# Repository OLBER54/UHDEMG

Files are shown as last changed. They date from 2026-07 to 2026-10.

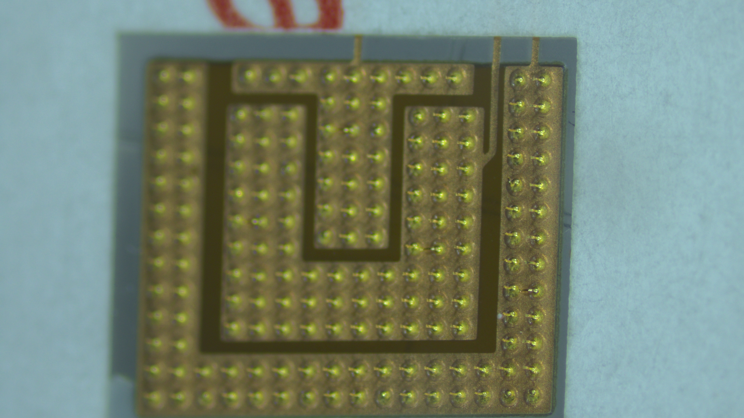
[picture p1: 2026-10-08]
Photos/UNeedles Sample/Tilt_Right_2.png

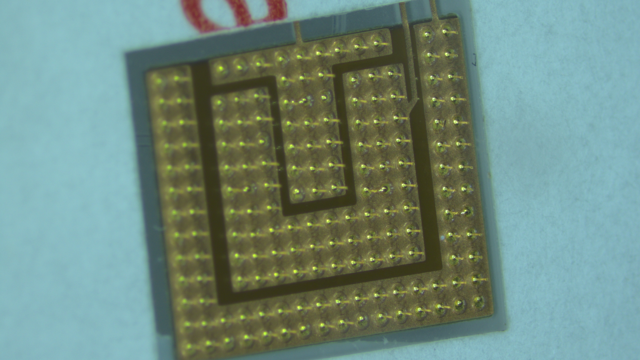
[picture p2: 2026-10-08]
Photos/UNeedles Sample/Tilt_Left_2.png

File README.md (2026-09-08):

Ultra-High-Density EMG Electrode Array
Development of an ultra-high-density electrode array for myoelectric signal acquisition and analysis, with a target of up to 512 electrodes spaced 5 mm apart. 
This project explores the use of a dense microneedle electrode array to support the evaluation of electromyography (EMG) signal analysis methods. Its motivating application is the control of hand prostheses using electrical signals generated by muscles.
The project addresses the limited electrode count and density highlighted in the project presentation, with the aim of providing a platform for more detailed analysis of muscle activity.

Objectives
- Develop an ultra-high-density electrode array for myoelectric signal acquisition.
- Evaluate and validate the performance of myoelectric signal analysis algorithms.
- Investigate EMG decomposition methods for studying motor unit activity.

Target Specifications
- Electrode count:	Up to 512
- Electrode: spacing	5 mm
- Electrode interface:	Microneedles at each electrode (23 microneedles per electrode)
- Recorded signals:	EMG
- Analysis focus: Algorithm evaluation and motor unit decomposition

Potential Applications
- Myoelectric hand prosthesis control.
- Muscle rehabilitation.
- Research supporting neurological disease diagnosis.

Files Architecture
- Archive: Old files
- Code: FPGA Verilog files, C++ PC application for collecting data and Matlab code for motor unit decomposition
- Presentations: Journal club, progess meeting and project summary
- Template Project Folder: Template used for altium projects
- UHDEMG: Electronic and mechanical files

PCB projects are on UHDEMG\01 - SCHEMAS ET PCB\99 - WORKING COPY
PCB Projects:
- DB_Panel: PCB panel of FPGA_DB and Electrode_Breakout
- Electrode_Breakout: PCB that connect to the electrode with headers on it.
- FPGA_DB: FPGA breakout board. Used to connect the FPGA to the INTAN modules boards
- RHD2132_64CH: INTAN modules to sample raw EMG data. Since the RHD2164 is not available, 2x RHD2132 are used in parallel to replace it. Up to 8 boards can be used at the same time to reach up to 512 electrodes.
- Microneedle_Patch: Flexible circuit board where microneedles are installed. 32 electrodes per FPC.
- Microneedle_Patch_Mirrored: Same as Microneedle_Patch, but the tail goes the other way, allowing to connect 64 electrodes to one RHD2132_64CH board.

Global_Project_Diagram

Electrode_Breakout_Diagram

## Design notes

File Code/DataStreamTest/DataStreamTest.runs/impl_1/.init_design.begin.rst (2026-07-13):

<?xml version="1.0"?>
<ProcessHandle Version="1" Minor="0">
    <Process Command=".planAhead." Owner="olivi" Host="LAPTOP-H85DCTKA" Pid="26048">
    </Process>
</ProcessHandle>

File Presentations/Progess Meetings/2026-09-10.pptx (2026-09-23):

## Updates

2026-09-10

## Design Issues

- RHD2164: B.O.
  - Had to redesign some of the boards
  - Main change: 1x RHD2164 -> 2x RHD2132
- All the redesigns are done
  - PCB review: In progress
  - BOM: Waiting on 1 quote only (RHD2132)

## Design Issue (Before)

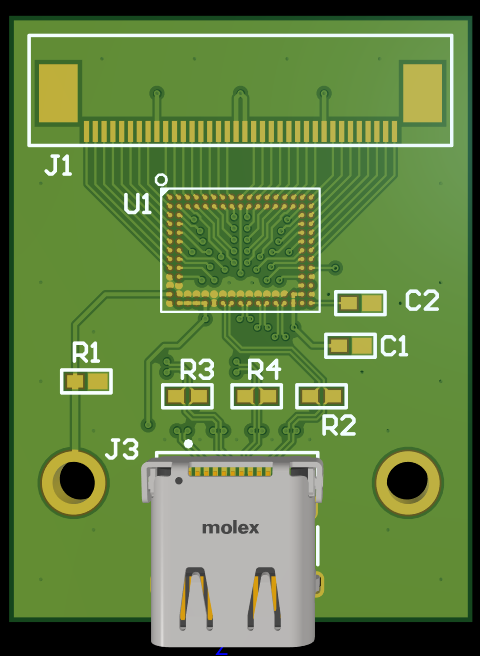
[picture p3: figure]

## Design Issue (After)

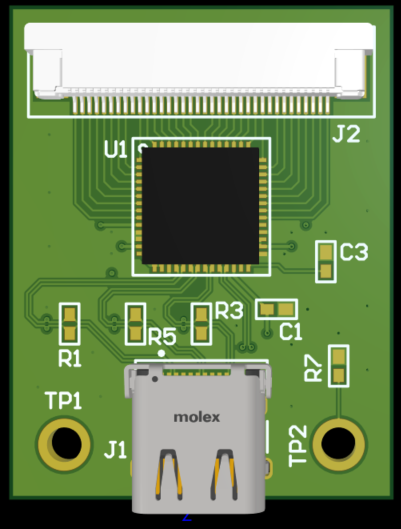
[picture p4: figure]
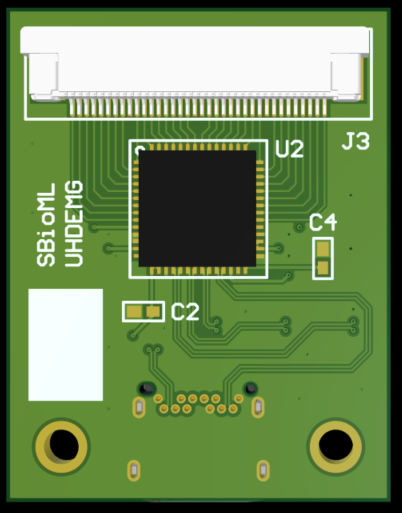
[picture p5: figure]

## Design Issue (Before)

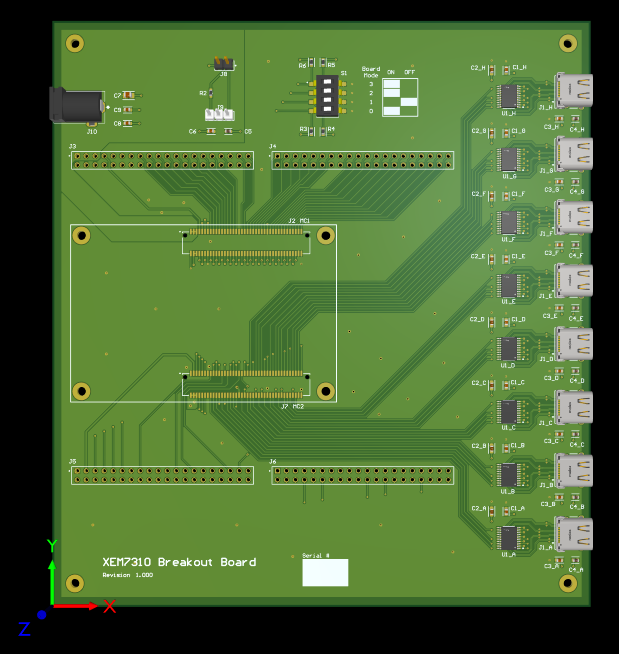
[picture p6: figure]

## Design Issue (After)

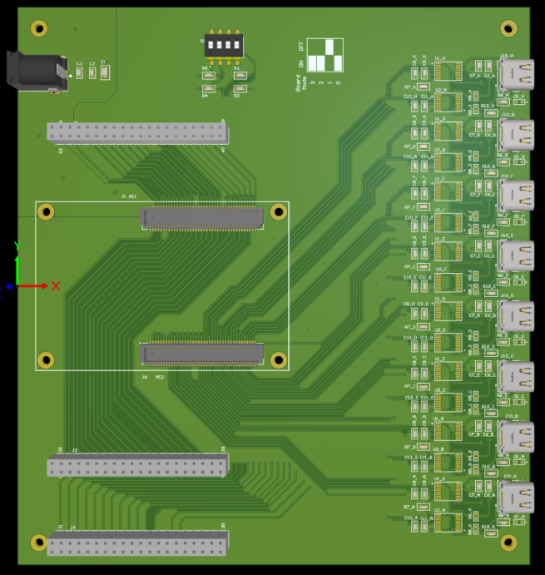
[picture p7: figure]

## Mechanical Setup

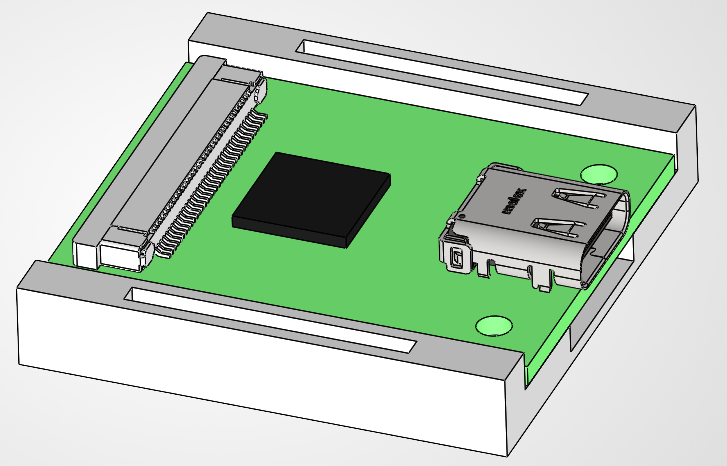
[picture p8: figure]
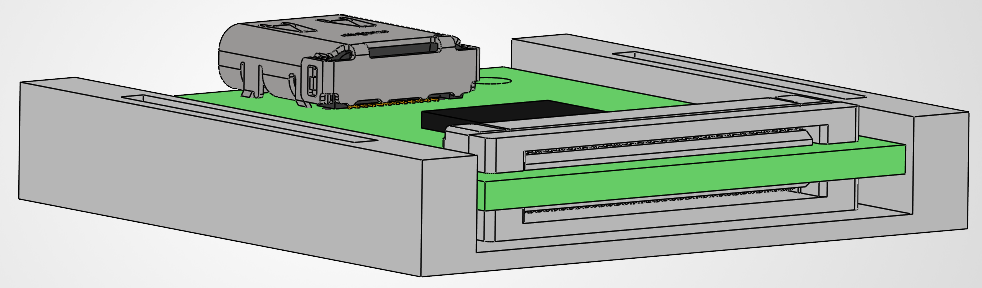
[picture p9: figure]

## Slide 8

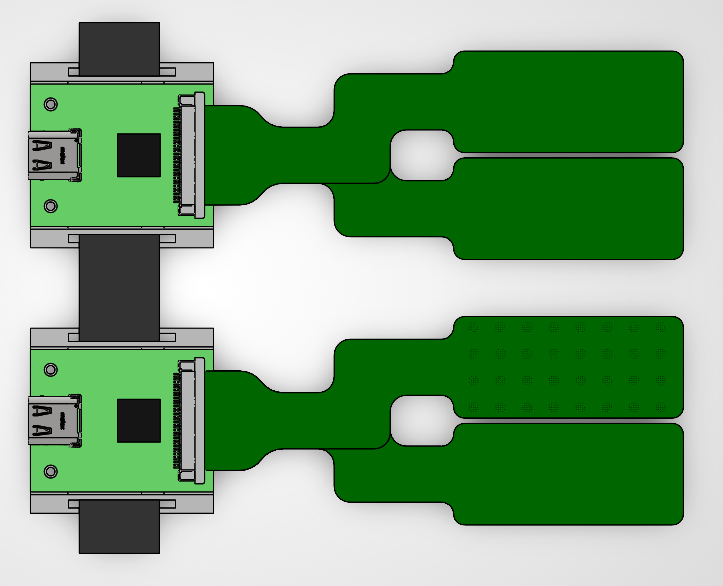
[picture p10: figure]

Hand

Elbow

## Next steps

- Scholarships applications
- PCB Review / Correct the designs / Order
- Test plans and protocol preparation
- Prepare code for collecting data

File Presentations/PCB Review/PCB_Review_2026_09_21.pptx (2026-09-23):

## PCB Review

Olivier Bergeron
2026/09/21

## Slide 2

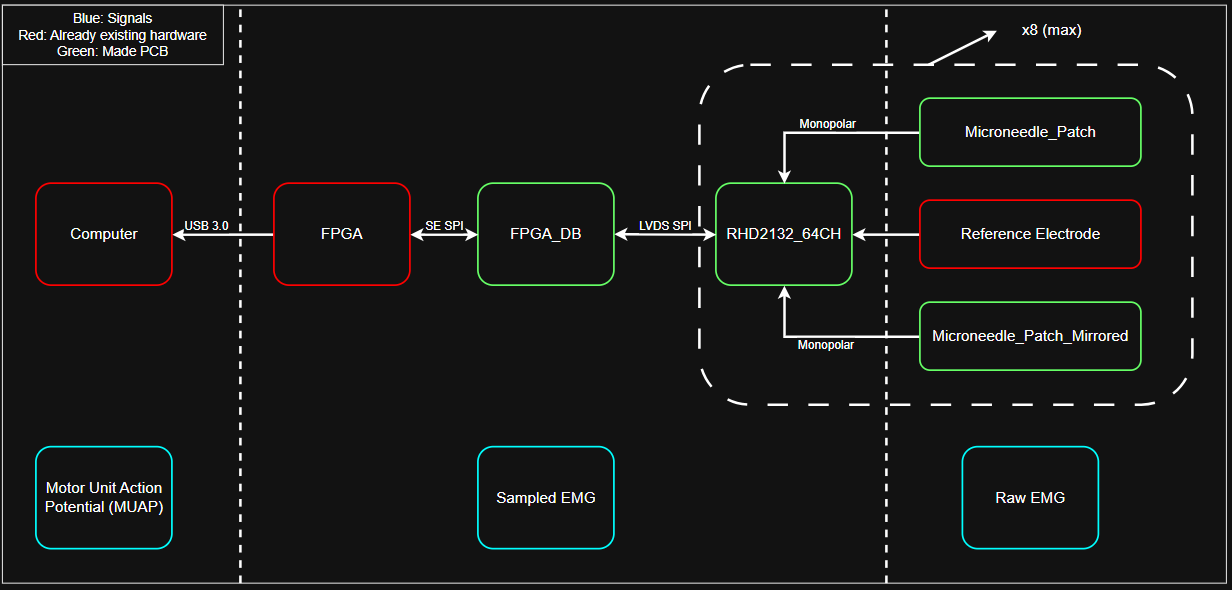
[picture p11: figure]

## Electrode Parameters

- Electrode
  - 2.5 mm diameter
  - 5 mm IED
  - 23 microneedle/electrode
    - 50 µm diameter
    - 400 µm long

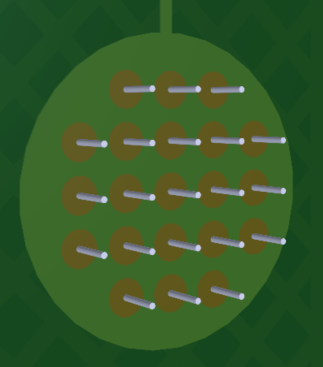
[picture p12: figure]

## Electrode Grid

- Grid size
  - 8 x 4
- For 1 patch
  - 32 electrodes
  - Up to 16 patches (512)
- Reference electrode
  - External Ag/AgCl

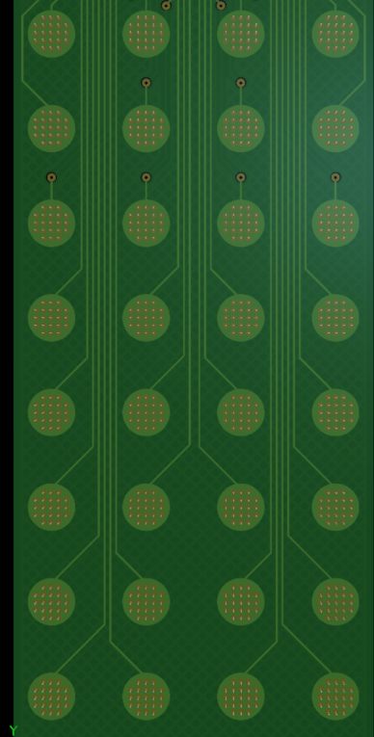
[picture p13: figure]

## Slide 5

Hand

Elbow

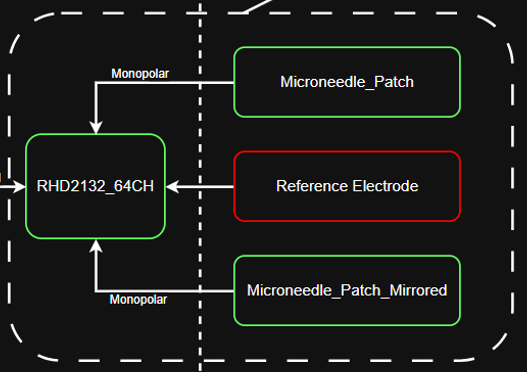
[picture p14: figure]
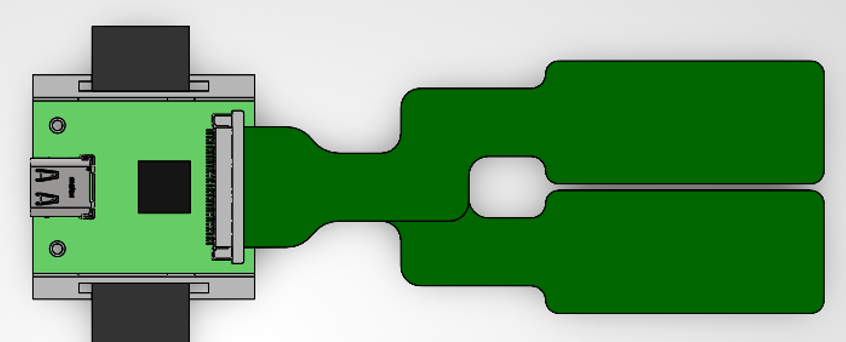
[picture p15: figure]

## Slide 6

Hand

Elbow

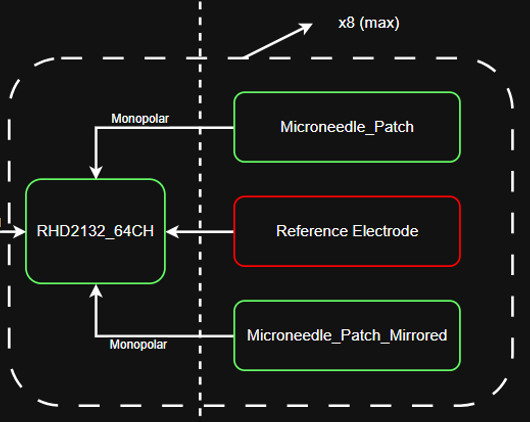
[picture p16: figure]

## From INTAN to FPGA

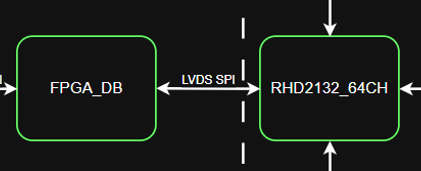
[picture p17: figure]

- For each RHD2132_64CH
  - 1 USB cable to FPGA board
  - 2x RHD2132 per board

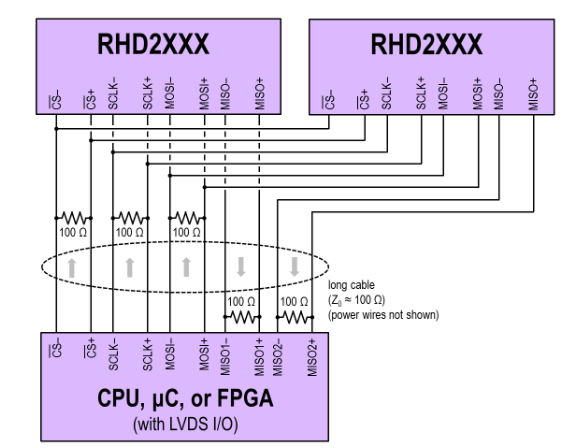
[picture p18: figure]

## From INTAN to FPGA

- 5 signals to transport
  - Can’t use the cable with redundancy
  - Need to check polarity
- Enable drivers with right polarity

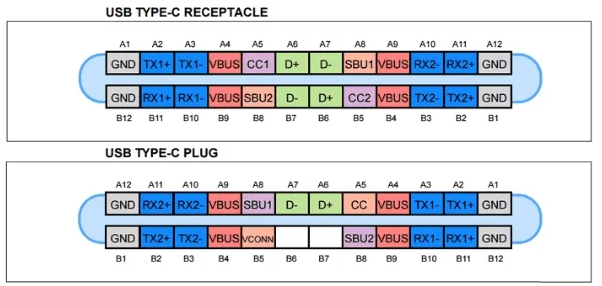
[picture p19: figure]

## From INTAN to FPGA

- FPGA Side
  - SBU 1: EN
  - SBU 2: EN
- RHD2132 Side
  - SBU 1: 3V3
  - SBU 2: 0V

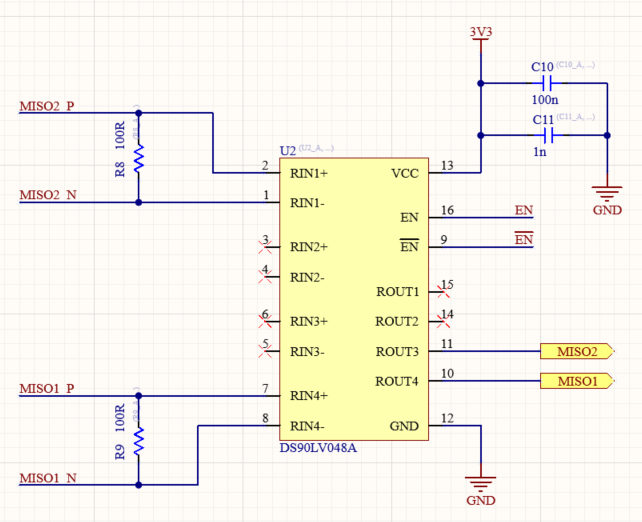
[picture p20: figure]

## FPGA Daughter Board

- USB connectors
  - Connect with RHD2132
- LVDS Drivers/Receivers
  - FPGA: Single Ended
  - RHD2132: LVDS

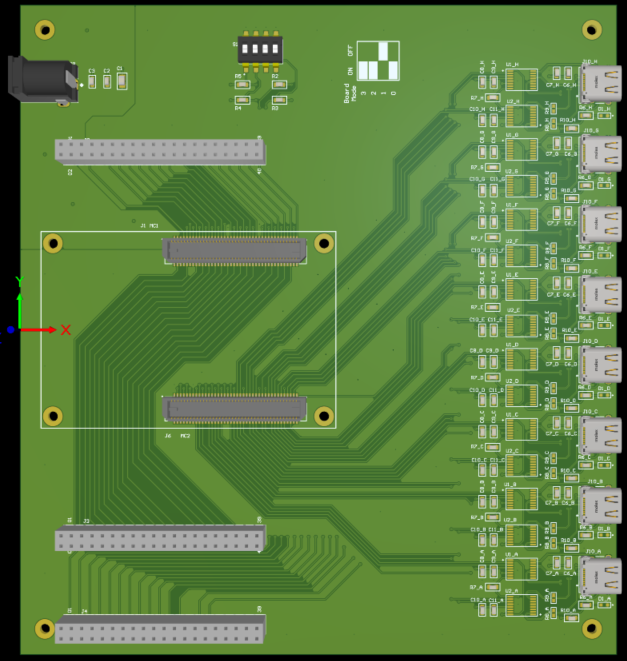
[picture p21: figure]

## Electrode Breakout Board

- For individual testing of electrode patches

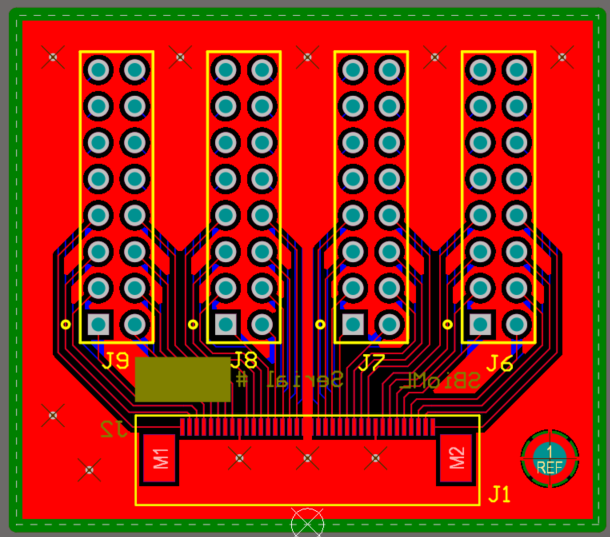
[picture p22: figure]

## Stackups

- FPGA_DB
  - Standard 4 layers PCB
  - 100 Ohms impedance (LVDS)
- Electrode Breakout
  - Standard 4 layers PCB

- RHD2132_64CH
  - 6 layers PCB
  - 100 Ohms impedance (LVDS)
- Electrode Patches
  - 2 layers FPC

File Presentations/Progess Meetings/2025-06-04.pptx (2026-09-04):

## Ressearch on benefits on higher electrode count on HD-EMG

## Is more better?

- Yes and no
- TL;DR
  - More will always be more precise
  - Diminishing returns
  - Algorithm dependant

## Main focus of articles

- Main focus of articles on HD-EMG: Reaching optimal number of electrode for algorithm, not density

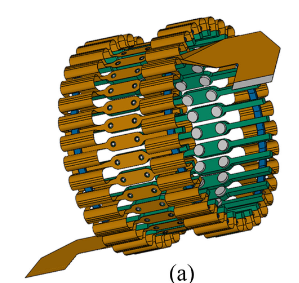
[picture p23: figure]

G. Rolandino, C. Zangrandi, T. Vieira, G. Luigi Cerone, B. Andrews, et J. J. FitzGerald, « HDE-Array: Development and Validation of a New Dry Electrode Array Design to Acquire HD-sEMG for Hand Position Estimation », IEEE Trans. Neural Syst. Rehabil. Eng., vol. 32, p. 4004‑4013, 2024, doi: 10.1109/tnsre.2024.3490796 (https://doi.org/10.1109/tnsre.2024.3490796).

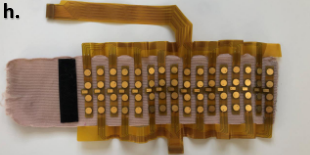
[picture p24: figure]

F. Chamberland et al., « Novel Wearable HD-EMG Sensor With Shift-Robust Gesture Recognition Using Deep Learning », IEEE Trans. Biomed. Circuits Syst., vol. 17, no 5, p. 968‑984, oct. 2023, doi: 10.1109/TBCAS.2023.3314053 (https://doi.org/10.1109/TBCAS.2023.3314053).

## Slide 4

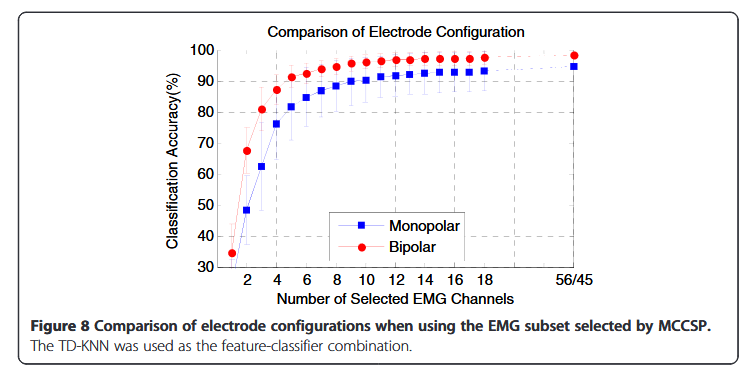
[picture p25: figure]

Y. Geng, X. Zhang, Y.-T. Zhang, et G. Li, « A novel channel selection method for multiple motion classification using high-density electromyography », BioMed Eng OnLine, vol. 13, no 1, p. 102, déc. 2014, doi: 10.1186/1475-925X-13-102 (https://doi.org/10.1186/1475-925X-13-102).

21 hand movements

Note: Some electrodes are on the hand for this study

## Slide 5

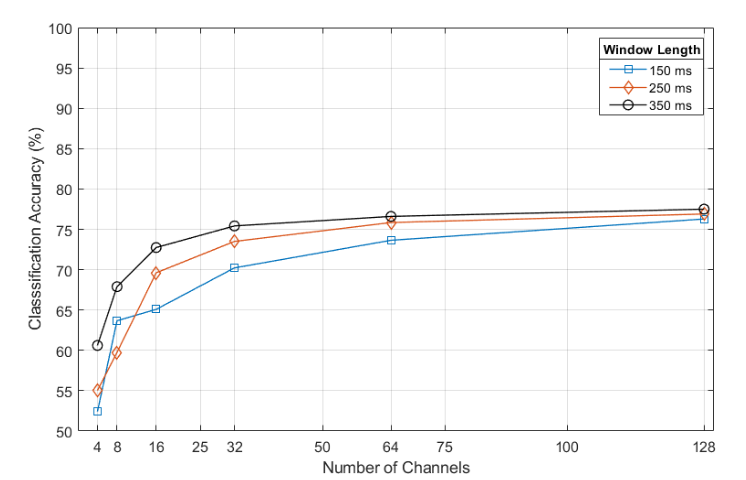
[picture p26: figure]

J. Lara, N. Paskaranandavadivel, et L. K. Cheng, « Effect of Segmentation Parameters on Classification Accuracy of High-Density EMG recordings », in 2019 41st Annual International Conference of the IEEE Engineering in Medicine and Biology Society (EMBC), Berlin, Germany: IEEE, juill. 2019, p. 6229‑6232. doi: 10.1109/EMBC.2019.8856809 (https://doi.org/10.1109/EMBC.2019.8856809).

9 hand movements

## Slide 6


M. Paleari, M. Di Girolamo, N. Celadon, A. Favetto, et P. Ariano, « On optimal electrode configuration to estimate hand movements from forearm surface electromyography », in 2015 37th Annual International Conference of the IEEE Engineering in Medicine and Biology Society (EMBC), Milan: IEEE, août 2015, p. 6086‑6089. doi: 10.1109/EMBC.2015.7319780 (https://doi.org/10.1109/EMBC.2015.7319780).

11 hand movements

J. Lara, N. Paskaranandavadivel, et L. K. Cheng, « HD-EMG Electrode Count and Feature Selection Influence on Pattern-based Movement Classification Accuracy », in 2020 42nd Annual International Conference of the IEEE Engineering in Medicine & Biology Society (EMBC), Montreal, QC, Canada: IEEE, juill. 2020, p. 4787‑4790. doi: 10.1109/EMBC44109.2020.9175210 (https://doi.org/10.1109/EMBC44109.2020.9175210).

17 hand movements

## Consequence of main focus

- Use of commercial hardware
- If focused on quantity: not focused on positionning


M. Paleari, M. Di Girolamo, N. Celadon, A. Favetto, et P. Ariano, « On optimal electrode configuration to estimate hand movements from forearm surface electromyography », in 2015 37th Annual International Conference of the IEEE Engineering in Medicine and Biology Society (EMBC), Milan: IEEE, août 2015, p. 6086‑6089. doi: 10.1109/EMBC.2015.7319780 (https://doi.org/10.1109/EMBC.2015.7319780).


J. Lara, N. Paskaranandavadivel, et L. K. Cheng, « Effect of Segmentation Parameters on Classification Accuracy of High-Density EMG recordings », in 2019 41st Annual International Conference of the IEEE Engineering in Medicine and Biology Society (EMBC), Berlin, Germany: IEEE, juill. 2019, p. 6229‑6232. doi: 10.1109/EMBC.2019.8856809 (https://doi.org/10.1109/EMBC.2019.8856809).

## Key design points

- Electrode geometry
- Inter-electrode distance (IED)
- Optimal resolution
- Computing power

## Electrode Geometry

- 2 main geometry
  - Pin: Circular electrode
  - Bar: Rectangular electrode
- Smaller electrode: Lower SNR
- Bigger electrode: Less precise information on signal and higher chance of crosstalk

## Inter-electrode distance (IED)

- IED: center to center distance between two electrodes
- Higher IED values: Higher chance of crosstalk and lower density
- Lower IED values: Lower SNR
  - Less impact on SNR than electrode dimensions

## Optimal resolution

- Resolution gain with adding electrodes:
  - Along the muscle fiber: small
  - Perpedicular to muscle fibers: big

## Computing power

- Higher quantity of electrodes: More computing power
- Main limiting factor for portable bracelet

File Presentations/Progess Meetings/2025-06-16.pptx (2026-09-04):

## Update

Olivier Bergeron
2025-06-16


## Trends looked for

- Number of electrodes vs electrode size
- Number of electrodes vs IED (Inter-electrode distance)
- Number of electrodes vs quantity of movement evaluated
- All of them were evaluated for a specific classification accuracy (90%)
- Major difficulty: only found 5 papers on varying electrode count and accuracy

## Trends looked for

- Quick conclusions:
  - Never the same amount of electrodes
  - Always a smart selection/position of electrodes
  - No paper got the same maximum classification accuracy
  - Some papers put electrodes on the hand
- Trends appear when taking in count percentage of electrode instead of absolute number of electrodes and classification accuracy relative to its max

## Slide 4


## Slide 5


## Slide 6


Logic trend: smaller electrodes -> lower signal amplitude -> need more electrodes

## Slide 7


Logic trend: closer electrodes -> smaller electrodes -> lower signal amplitude -> need more electrodes

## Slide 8


Trend seems to look like more movements requires a little more electrodes

## Next trend to look for

- Number of detectable motor units vs number of electrodes
- As of right now: only found 1 paper
A. H. Caillet et al., « Larger and Denser: An Optimal Design for Surface Grids of EMG Electrodes to Identify Greater and More Representative Samples of Motor Units », eNeuro, vol. 10, no 9, p. ENEURO.0064-23.2023, sept. 2023, doi: 10.1523/ENEURO.0064-23.2023 (https://doi.org/10.1523/ENEURO.0064-23.2023).

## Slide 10


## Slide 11


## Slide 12


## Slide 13


## Partial conclusions

- Going denser:
  - Tends to give a little more accuracy
  - Seems to give more detectable motor units

## Next steps

- Keep trying to find papers on motor unit detection vs quantity of electrodes

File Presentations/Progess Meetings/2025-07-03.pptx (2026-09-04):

## Updates

Olivier Bergeron


## Since last time

- Two main goals
  - 1- Keep searching for articles for correlation between electrode count and classification accuracy
    - Didn’t find any more valuable article as of right now
  - 2- Find more articles about motor unit decomposition

## Motor Unit

- Definition: A motor unit consist of a motor neuron and all the muscle fibers innervated by the axon.
- Smallest functional unit of voluntary muscle activation


S. K. Gollapudi, J. J. Michael, and M. Chandra, Striated Muscle Dynamics, Reference Module in Biomedical Sciences. Elsevier, 2014. doi: 10.1016/B978-0-12-801238-3.00251-8 (https://doi.org/10.1016/B978-0-12-801238-3.00251-8).

## Motor unit vs EMG


D. Farina et A. Holobar, « Characterization of Human Motor Units From Surface EMG Decomposition », Proc. IEEE, vol. 104, no 2, p. 353‑373, févr. 2016, doi: 10.1109/JPROC.2015.2498665 (https://doi.org/10.1109/JPROC.2015.2498665).

## Motor Unit Decomposition

- Multiples techniques for extracting motor units spike trains
  - Blind Source Separation
    - Separates mixed signals into their original independent sources without prior knowledge of the mixing process.
  - Convolution Kernel Compensation
    - Reconstructs motor unit spike trains by compensating for the convolution effect of motor unit action potentials in EMG signals.
  - Template matching + clustering
    - Detects and classifies recurring signal patterns (spikes) by comparing them to learned templates and grouping similar ones into clusters.

## What information can be extracted

- Firing rate of motor units
- Recruitment order
- Spike timing
- Spatial location

## Pros with motor unit decomposition

- Ability to find subtle gestures
  - Some EMG patterns overlap for different motor unit activity
- High quantity of recognisable gestures with high classification accuracy
  - Example of quantity of gestures: 12 (94.6%)¹, 66 (≥ 89%)²
- High classification accuracy
  - Around the same as CNN

[1] C. Chen, Y. Yu, X. Sheng, J. Meng, et X. Zhu, « Real-Time Hand Gesture Recognition by Decoding Motor Unit Discharges Across Multiple Motor Tasks From Surface Electromyography », IEEE Trans. Biomed. Eng., vol. 70, no 7, p. 2058‑2068, juill. 2023, doi: 10.1109/TBME.2023.3234642 (https://doi.org/10.1109/TBME.2023.3234642).
[2] M. Montazerin, E. Rahimian, F. Naderkhani, S. F. Atashzar, S. Yanushkevich, et A. Mohammadi, « Transformer-based hand gesture recognition from instantaneous to fused neural decomposition of high-density EMG signals », Sci Rep, vol. 13, no 1, p. 11000, juill. 2023, doi: 10.1038/s41598-023-36490-w (https://doi.org/10.1038/s41598-023-36490-w).

## Cons with motor unit decomposition

- Highly sensitive to electrode shift
  - Often required to re-decompose the motor units when shifting happens
- More “hardware hungry”
  - Decompositions methods are more computationally intensive
  - More power is needed
  - Very difficult for real-time application
- Highly sensitive to positioning
  - Misalignments/changes in contact degrades motor unit tracking quality
  - When redonned, recalibration is required

## What if: hybrid method

- Hybrid method: Combine motor unit decomposition with CNN features
- Why?
  - Robustness, fast computing and general hand gestures with CNN
  - Fine neural control details with motor unit decomposition

## What if: hybrid method

- Methods examples
  - Early fusion: Concatenate EMG + Motor Unit into one input
  - Late fusion: Two separate classifier fused at decision level
  - Joint fusion: Models with dual-branches and adaptive weighting
- Applications
  - High gesture count applications
  - Benchmarking upper limits of classification performance

## Pros and Cons

- Pros
  - Combining increase accuracy
  - More gesture recognition
  - Can give neural control information
- Cons
  - High computing cost
  - Very hard for wearable devices
  - High sensibility with steep performance reduction risk

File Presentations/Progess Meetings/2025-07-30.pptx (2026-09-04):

## Avancements

Olivier Bergeron


## Since last time

- Project finally got defined
  - Design a HD-EMG forearm sleeve with high count of electrodes (≥ 256 channels) aimed at detecting and decomposing motor unit activity to enable accurate hand movement recreation in an offline environment.
  - Definition still w.i.p.
- Start defining project needs/goals
  - Multiple categories
    - Mechanical
    - Electronics
    - Firmware
    - Software

## Mechanical Design

- First major design phase
- Sleeve design
  - Structure (Material, Shape, Size)
  - Electrode design (Material, Size, Positioning, Quantity)
  - Cable management
  - Ease of use
- Design approach: Custom

## Electronic Design

- Second major design phase
- Data acquisition design
  - Acquisition module (Data to be read by an FPGA)
  - FPGA module for acquisition
  - GPU module for software use
- Design approach: Not fully defined, but might go with overkill already existing design (try to avoid having it as a bottleneck)

## Firmware Design

- Third major design phase
- Data acquisition code
  - Program the FPGA to get all the channels and transfer the data to a GPU
  - Sampling frequency objective: 2 kHz

## Software Design

- Last major design phase
- Algorithm implementation
  - Use of motor unit decomposition algorithms to reconstruct hand movements

## Some start of mechanical design

- Context: Electrodes needs to be small and close to each other for motor unit decomposition
- Rule of thumb: IED ≈ 2 x Electrode diameter
  - With a small electrode diameter
    - More motor units will be detectable
    - Noisier the signal will be
    - Sweet spot seems to be between 2 mm and 4 mm

## Some start of mechanical design

- Example
  - 265 mm circumference where the sleeve will be
  - With an IED of 4 mm => approx. 67 electrodes needed for 1 row of electrodes
  - If we want 256 electrodes max => only 3 columns are possible
- Three possible approaches:
  - 1- More electrodes
  - 2- Increase IED (Higher and/or asymmetrical values)
  - 3- Half sleeve instead of full sleeve

## Some start of mechanical design

- What have been found so far
  - Avoid half sleeve because of less detectable motor units
  - Asymmetrical IED values, since circumferential coverage is more important than longitudinal coverage
  - To keep electrodes small and close, higher electrode count will be needed
- First draft: 60 x 8 grid with circumferential IED close to 4 mm and longitudinal IED of 10 mm

## Next steps

- Figure out if there is a maximum of channels electronic wise
- Try different grid values
- Simulate coverage when forearm size change

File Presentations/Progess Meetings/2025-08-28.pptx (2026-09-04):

## Update

Olivier Bergeron
28/08/2025


## Since last time

- Last grid draft:
  - 61 x 8 electrodes
  - 488 electrodes in total
  - 2 mm diameter
  - Circumference IED = [4; 5] mm
  - Length IED = 10 mm

## Modifications

- Problem with rectangular grid: non uniform IED
  - The further from the muscle belly, the closer the electrodes
  - Solution: Lower the electrode count for the rows further from the belly
- Other modification: remove the last row
  - Goal: Reduce the electrode count without any major impact

## Modifications

- Problem with rectangular grid: non uniform IED
  - The further from the muscle belly, the closer the electrodes
  - Solution: Lower the electrode count for the rows further from the belly
- Problem with IED constrain not enough wiggle room for covering average sizes
  - Size range (circumference) = [210; 290] mm
  - Solution: 2 sizes
- Other modification: remove the last row
  - Goal: Reduce the electrode count without any major impact

## Modifications

- Problem with rectangular grid: non uniform IED
  - The further from the muscle belly, the closer the electrodes
  - Solution: Lower the electrode count for the rows further from the belly
- Problem with IED constrain not enough wiggle room for covering average sizes
  - Size range at maximum size (circumference) = [210; 290] mm
  - Solution: 2 sizes
- Other modification: remove the last row
  - Goal: Reduce the electrode count without any major impact

## New draft


Note:
Minimal coverage: Minimum arm size (IED = 4 mm)
Maximal coverage: Maximum arm size (IED = 5 mm)
Initial Draft: 488 electrodes in total

## Next Steps

- Scholarship applications (W.I.P.)
- 3D view of the sleeves (W.I.P.)
- Start looking at electrode fabrication processes

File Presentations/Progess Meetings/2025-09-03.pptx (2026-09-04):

## Objectif

- Objectif: Reconstruction des mouvements de la main à l’aide de la decomposition des signaux EMG en potentiel d’action d’unités motrice (MUAP)


D. Farina et R. Merletti, Éd., Surface electromyography: physiology, engineering, and applications. in IEEE Press Series on Biomedical Engineering. Piscataway, NJ: IEEE Press, 2016. doi: 10.1002/9781119082934 (https://doi.org/10.1002/9781119082934).

## Cahier des charges

- Électrodes
  - Diamètre: 2 mm
  - Distance inter-electrode:
    - [4; 5] mm en circonférence
    - 10 mm sur la longueur
  - Quantité: 398
- Montage méchanique:
  - Flexibilité
  - Élasticité

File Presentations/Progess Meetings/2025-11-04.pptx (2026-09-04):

## Update

Olivier Bergeron


## PEDOT article no 1

- Conducting Polymer-Ionic Liquid Electrode Arrays for High-Density Surface Electromyography (Velasco-Bosom et al.)
- Key points
  - Grid size: 4 x 4
  - Electrode size: 1.5 mm x 1.5 mm
  - IED: 3 mm
  - Scalable fabrication techniques


## PEDOT article no 2

- Stretchable and Self-Adhesive PEDOT:PSS Blend with High Sweat Tolerance as Conformal Biopotential Dry Electrodes (Cao et al.)
- Key points
  - Blend of PEDOT, Polyvinyl alcohol and tannic acid
  - Lower peak noise than Ag/AgCl (20 µV vs 60 µV)
  - Stretchable with minimal resistance change (up to 50% stretch)
  - Self-adhesive on dry and sweaty skin


## Pre-made kits - TMSi

- Electrode grid
  - 4 mm IED
  - 2 mm diameter (not written but assumed)
  - 32 and 64 channels available
  - Textile grids
- Wireless acquisition module
- Free software
  - Motor unit decomposition


## Pre-made kits - Ot Bioelettronica

- Electrode Grid
  - 5 mm IED
  - 2.5 mm diameter (not written but assumed)
  - 32 channels available
- Acquisition module
  - High channel count available (384 or 960)


## Pre-made kits - Delsys

- Electrode grid
  - 2 mm diameter
  - 6 mm IED
  - Hard to generate bigger grid
- Paid software
  - API available
  - Motor Unit Decomposition


## Explorable solution

- Main issue: acquisition modules very expensive
  - Possible solution: Custom made acquisition system
    - Could be tested with commercial grid

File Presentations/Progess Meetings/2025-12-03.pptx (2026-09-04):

## Presentation & Updates

Olivier Bergeron


## Project Presentation

- EMaGer: Spatial EMG activation maps with 64 electrodes


F. Chamberland et al., « EMaGer: A Wearable Full-Circumference HD-EMG Sensor and Data Augmentation Method for Robust Hand Gesture Recognition », in 2023 45th Annual International Conference of the IEEE Engineering in Medicine & Biology Society (EMBC), Sydney, Australia: IEEE, juill. 2023, p. 1‑5. doi: 10.1109/EMBC40787.2023.10340612 (https://doi.org/10.1109/EMBC40787.2023.10340612).

## Project Presentation


- Hypothesis: More channels would result more recognisable gestures.


A. H. Caillet et al., « Larger and Denser: An Optimal Design for Surface Grids of EMG Electrodes to Identify Greater and More Representative Samples of Motor Units », eNeuro, vol. 10, no 9, p. ENEURO.0064-23.2023, sept. 2023, doi: 10.1523/ENEURO.0064-23.2023 (https://doi.org/10.1523/ENEURO.0064-23.2023).

## Project Presentation

Electrode Grid

Analog Front End (AFE)

Analog to Digital Converter (ADC)

Post-processing
(MUAP Decomposition)

FPGA

## Project Presentation

- Electrode grid: Custom made
  - Grid size: 7 x 51 (357 total)
  - Electrode dimensions: ~ 2.5 mm
  - Inter-electrode distance (IED): ~ 5 mm (Circ.) and ~ 10 mm (Long.)
- AFE & ADC:
  - High number of channels (448 or 512)
  - Hardware options: Pre-made (TMSi, OT Bioelettronica, etc.), custom with INTAN or fully custom.
- Post-processing
  - Hardware not fully defined but gravitate towards GPU.

## Updates

- PEDOT process:
  - Found interesting articles.
  - Will send them to Ricardo to review.
- Prototype quotes:
  - TMSi: Want to set up a meeting to discuss.
  - OT Bioelettronica: Affordable grid, but not the acquisition module

## Updates


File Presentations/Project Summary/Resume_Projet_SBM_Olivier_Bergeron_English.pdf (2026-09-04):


# - Context: Control of hand prostheses through the analysis of myoelectric signals (generated by muscles)

# - Use of electrodes for signal acquisition

# - Common on the market:

## - Low number of electrodes for prosthesis control

# - Problems

## - Low electrode count/density

1

Steeper Group, “Electrodes & Cables,” Steeper Group. [Online]. [Accessed: Jul. 10, 2026]

F. Chamberland et al., « EMaGer: A Wearable Full-Circumference HD-EMG Sensor and Data Augmentation Method for Robust Hand Gesture Recognition », dans 2023 45th Annual International Conference of the IEEE Engineering in Medicine & Biology Society (EMBC), Sydney, Australia: IEEE, juill. 2023, p. 1-5


## - Project: Development of an ultra-high-density electrode array

- Up to 512 electrodes
- 5 mm between each electrode
- Microneedles for each electrode


## - Objective:

- Validate the performance of myoelectric signal analysis algorithms
- Test a myoelectric signal analysis method

## - Decomposition of signals into motor neuron impulses (Motor Unit Action Potentials)

## - Allows the behavior of motor neurons to be analyzed at the source

## - Potential applications:

- Prostheses
- Muscle rehabilitation
- Diagnosis of neurological diseases

2

K. Haider, T. Tilly, V. Coyle, et C. Dalton, « Scalable and Customizable Trimaterial Microneedle Electrochemical Biosensor Platform With Cleanroom-Free Fabrication », IEEE Sens. Lett., vol. 9, no 9, p. 1-4, sept. 2025
D. Farina et A. Holobar, « Characterization of Human Motor Units From Surface EMG Decomposition », Proc. IEEE, vol. 104, no 2,
p. 353-373, févr. 2016

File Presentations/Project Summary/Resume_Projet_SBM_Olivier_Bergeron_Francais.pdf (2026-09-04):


# - Contexte: Contrôle de prothèses de main via l’analyse des signaux myoélectriques (générés par les muscles)

# - Utilisation d’électrodes pour la capture

# - Populaire sur le marché:

## - Faible quantité d’électrodes pour le contrôle d’une prothèse

# - Problèmes

## - Faible quantité/densité

1

Steeper Group, “Electrodes & Cables,” Steeper Group. [Online]. [Accessed: Jul. 10, 2026]

F. Chamberland et al., « EMaGer: A Wearable Full-Circumference HD-EMG Sensor and Data Augmentation Method for Robust Hand Gesture Recognition », dans 2023 45th Annual International Conference of the IEEE Engineering in Medicine & Biology Society (EMBC), Sydney, Australia: IEEE, juill. 2023, p. 1-5


## - Projet: Création d’une matrice d’électrode d’ultra haute densité

## - Jusqu’à 512 électrodes - 5 mm entre chaque électrode - Microaiguilles pour chaque électrode

## - Objectif:

## - Valider la performance des algorithmes d’analyse de signaux myoélectriques - Tester une méthode d’analyse des signaux myoélectriques


## - Décomposition des signaux en impulsions des neurones moteurs (Potentiel d’action de l’unité motrice)

## - Permet d’analyser le comportement des neurones moteurs à la source

## - Applications potentielles:

## - Prothèses - Réhabilitation musculaire - Diagnostique des maladies neurologiques

2

K. Haider, T. Tilly, V. Coyle, et C. Dalton, « Scalable and Customizable Trimaterial Microneedle Electrochemical Biosensor Platform With Cleanroom-Free Fabrication », IEEE Sens. Lett., vol. 9, no 9, p. 1-4, sept. 2025
D. Farina et A. Holobar, « Characterization of Human Motor Units From Surface EMG Decomposition », Proc. IEEE, vol. 104, no 2,
p. 353-373, févr. 2016

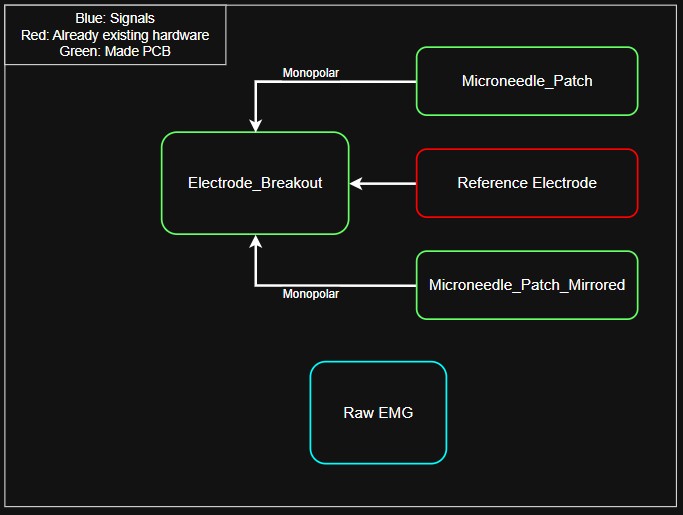
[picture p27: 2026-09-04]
UHDEMG/03 - NOTES DE CONCEPTION/Electrode_Breakout_Diagram.png

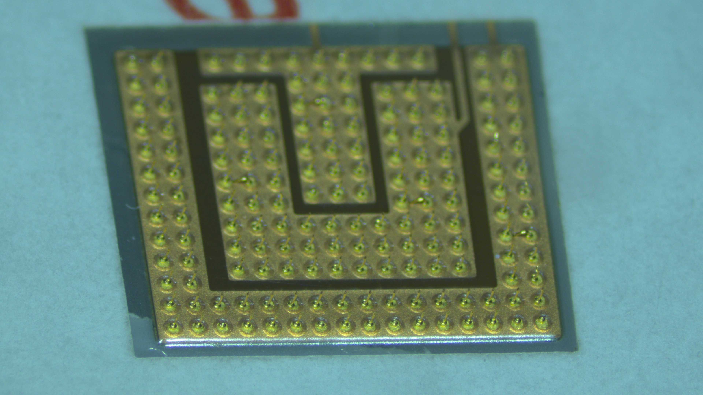
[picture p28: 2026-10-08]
Photos/UNeedles Sample/Tilt_Front_1.png

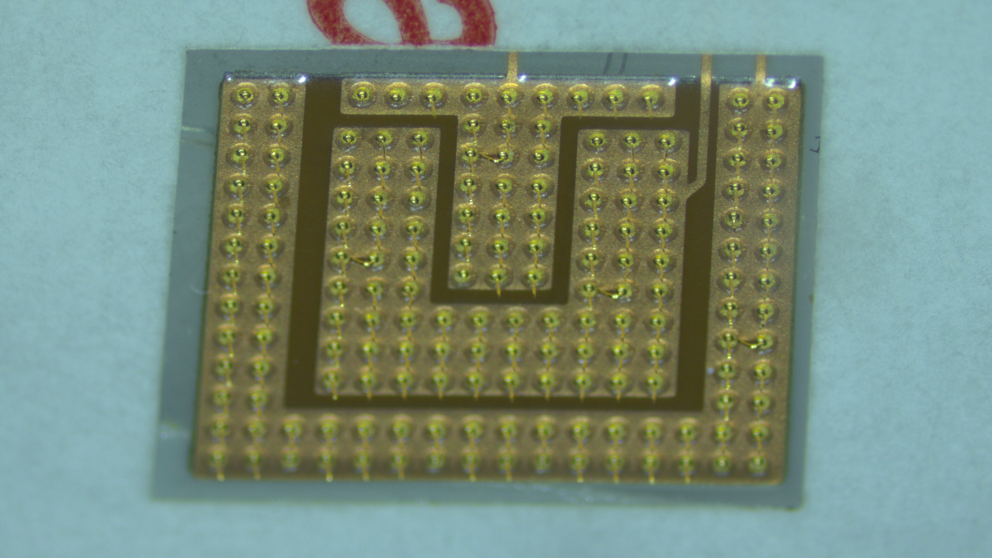
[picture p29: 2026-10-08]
Photos/UNeedles Sample/Tilt_Back_1.png

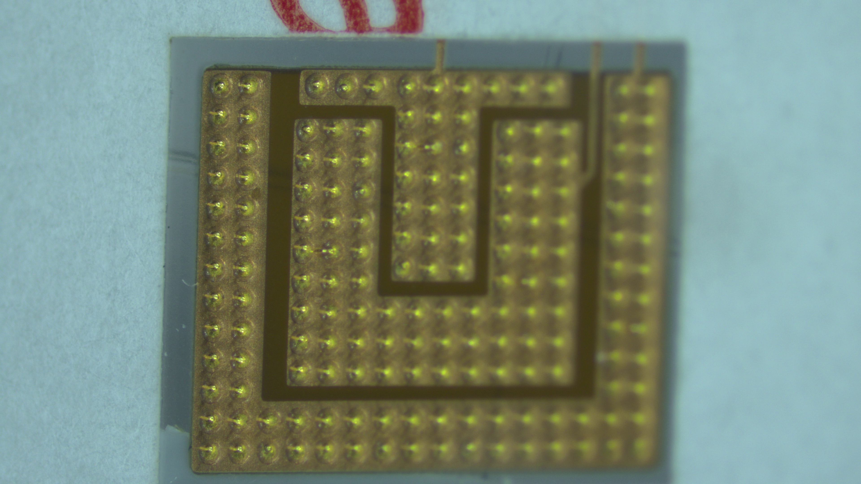
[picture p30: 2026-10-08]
Photos/UNeedles Sample/Tilt_Right_1.png

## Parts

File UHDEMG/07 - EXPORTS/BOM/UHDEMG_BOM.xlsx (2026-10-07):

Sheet: Summary
Manufacturer/Distributor | Amount
Digikey | $392.03
PCBWay | $1433.04
Intan | $10029.59
Miscellaneous | $8.91
Total | $11863.56

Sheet: PCBWAY
Project Name | Cost | Cost (CAD)
DB_Panel | $278.73 | $395.80
Microneedle_Patch | $247.54 | $351.51
Microneedle_Patch_Mirrored | $247.54 | $351.51
RHD2132_64CH | $235.37 | $334.23
Total |  | $1433.04

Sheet: Digikey
Digikey
Cart Link | https://www.digikey.ca/short/82rprr5v
Cart Total | $392.03
Index | Quantity | Part Number | Manufacturer Part Number | Description | Available | Backorder | Unit Price | Extended Price CAD
1 | 3 | 296-51824-1-ND | TLV9001TIDCKR | IC OP AMP 1CH SC-70-5 | 3 | 0 | 0.72 | 2.16
2 | 2 | 1168-TG-T1000-36-36-0.25-5PT-ND | TG-T1000-36-36-0.25-5PT | THERM TAPE 36X36MM W/ADH WHT | 2 | 0 | 0.63 | 1.26
3 | 2 | 2223-HSB02-101007-ND | HSB02-101007 | HEAT SINK, BGA, 10 X 10 X 7 MM | 2 | 0 | 1.23 | 2.46
4 | 1 | 2223-HSB31-212105-ND | HSB31-212105 | HEAT SINK, BGA, 21 X 21 X 5 MM | 1 | 0 | 1.48 | 1.48
5 | 25 | 17-3-2492104-6CT-ND | 3-2492104-6 | 0.5MM FPC RIGHT ANGLE BOTTOM SMT | 25 | 0 | 1.6392 | 40.98
6 | 18 | 12401610E4#2ACT-ND | 12401610E4#2A | CONN RCP USB3.1 TYPEC 24P SMD RA | 18 | 0 | 1.784 | 32.11
7 | 10 | 612-SSW-108-01-G-D-ND | SSW-108-01-G-D | CONN RCPT 16POS 0.1 GOLD PCB | 10 | 0 | 3.261 | 32.61
8 | 10 | DS90LV048ATMTC/NOPB-ND | DS90LV048ATMTC/NOPB | IC RX 16-TSSOP | 10 | 0 | 4.578 | 45.78
9 | 10 | DS90LV047ATMTC/NOPB-ND | DS90LV047ATMTC/NOPB | IC DRVR 16-TSSOP | 10 | 0 | 4.75 | 47.50
10 | 50 | 311-100LRCT-ND | RC0402FR-07100RL | RES 100 OHM 1% 1/16W 0402 | 50 | 0 | 0.0188 | 0.94
11 | 30 | 311-10.0KHRCT-ND | RC0603FR-0710KL | RES 10K OHM 1% 1/10W 0603 | 30 | 0 | 0.0292 | 0.88
12 | 10 | 311-0.0GRCT-ND | RC0603JR-070RL | RES 0 OHM JUMPER 1/10W 0603 | 10 | 0 | 0.019 | 0.19
13 | 10 | 311-0.0LRCT-ND | RC0402FR-070RL | RES 0 OHM JUMPER 1/16W 0402 | 10 | 0 | 0.016 | 0.16
14 | 15 | 311-330HRCT-ND | RC0603FR-07330RL | RES 330 OHM 1% 1/10W 0603 | 15 | 0 | 0.039 | 0.59
15 | 2 | SAM8995-ND | TSW-103-07-F-S | CONN HEADER VERT 3POS 2.54MM | 2 | 0 | 0.25 | 0.50
16 | 2 | SAM8858-ND | SNT-100-BK-G | CONN SHUNT 2POS | 2 | 0 | 0.48 | 0.96
17 | 3 | SAM9060-ND | BTE-040-01-F-D-A | CONN HDR 80POS SMD GOLD | 3 | 0 | 5.03 | 15.09
18 | 2 | CP-102AH-ND | PJ-102AH | CONN PWR JACK 2X5.5MM SOLDER | 2 | 0 | 1.13 | 2.26
19 | 10 | 612-SSW-108-01-G-D-ND | SSW-108-01-G-D | CONN RCPT 16POS 0.1 GOLD PCB | 10 | 0 | 3.261 | 32.61
20 | 4 | SAM10036-ND | SSW-120-01-F-D | CONN RCPT 40POS 0.1 GOLD PCB | 4 | 0 | 6.27 | 25.08
21 | 10 | 754-1934-1-ND | APT1608LZGCK | LED GREEN CLEAR 2SMD | 10 | 0 | 0.589 | 5.89
22 | 2 | 2223-DS04-254-2-04BK-SMT-CT-ND | DS04-254-2-04BK-SMT-TR | SWITCH SLIDE DIP SPST 0.025A 24V | 2 | 0 | 1.26 | 2.52
23 | 50 | 311-1088-1-ND | CC0603KRX7R7BB104 | CAP CER 0.1UF 16V X7R 0603 | 50 | 0 | 0.0812 | 4.06
24 | 25 | 490-1313-1-ND | GRM155R71C103KA01D | CAP CER 10000PF 16V X7R 0402 | 25 | 0 | 0.035 | 0.88
25 | 50 | 311-1338-1-ND | CC0402KRX7R7BB104 | CAP CER 0.1UF 16V X7R 0402 | 50 | 0 | 0.0408 | 2.04
26 | 20 | 445-1604-1-ND | C1608X7R1C105K080AC | CAP CER 1UF 16V X7R 0603 | 20 | 0 | 0.101 | 2.02
27 | 50 | 311-4063-1-ND | CC0603KRX7R7BB102 | CAP CER 1000PF 16V X7R 0603 | 50 | 0 | 0.054 | 2.70
28 | 4 | 1276-7092-1-ND | CL21A226KOQNNNG | CAP CER 22UF 16V X5R 0805 | 4 | 0 | 0.62 | 2.48
29 | 25 | A122528-ND | 130522 | CONN SPADE TERM 16-22AWG M2.5 | 25 | 0 | 0.6776 | 16.94
30 | 1 | 839-10-06147-ND | 10-06147 | CABLE, 2000 MM, 50-01071 USB C P | 1 | 0 | 15.84 | 15.84

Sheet: Intan
 | Qt | Unit Price | Handling | Shipping | Total | Total CAD
RHD2132 | 16 | $430.00 | $50.00 | $133.09 | $7063.09 | $10029.59

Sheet: Miscellaneous
Name | Vendor | Part Number | Qt | Unit Price | Total Price
Bolts | McMaster-Carr | 92000A011 | 1 | 8.91 | $8.91

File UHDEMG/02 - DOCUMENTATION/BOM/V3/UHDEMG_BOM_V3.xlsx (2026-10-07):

Category | Name | Electrode Breakout | FPGA DB | RHD2132 | Total
Qt Assemblies |  | 2 | 1 | 8
Connectors | ZIF | 2 | 0 | 2 | 20
 | USB | 0 | 8 | 1 | 16
 | FPGA | 0 | 2 | 0 | 2
 | Power | 0 | 1 | 0 | 1
 | Header 1X3 (+ Jumper) | 0 | 1 | 0 | 1
 | Header 2X8 | 4 | 0 | 0 | 8
 | Header 2X20 | 0 | 3 | 0 | 3
Resistors | 0402 0R00 | 1 | 0 | 0 | 2
 | 0402 100R | 0 | 16 | 3 | 40
 | 0603 0R00 | 0 | 1 | 0 | 1
 | 0603 330R | 0 | 8 | 0 | 8
 | 0603 10K0 | 0 | 22 | 0 | 22
Capacitors | 0402 10n | 0 | 0 | 2 | 16
 | 0402 100n | 0 | 0 | 2 | 16
 | 0603 1n | 0 | 16 | 0 | 16
 | 0603 100n | 0 | 26 | 0 | 26
 | 0603 1u | 0 | 9 | 0 | 9
 | 0805 22u | 0 | 1 | 0 | 1
Diodes | Green LED | 0 | 8 | 0 | 8
IC | TLV9001 | 0 | 1 | 0 | 1
 | Driver | 0 | 8 | 0 | 8
 | Receiver | 0 | 8 | 0 | 8
Switches | DIP | 0 | 1 | 0 | 1
 |  |  |  |  |  | *Screw Lengths
Assemblies | Heatsink FPGA | 0 | 3 | 0 | 3 | RHD2132: 4.6 mm max
 | Heatsink Tape | 0 | 2 | 0 | 2 | FPGA: 10.08 mm max
* | M2 Screw | 2 | 4 | 2 | 24 | Electrode: 6 mm max
 | Electrode Wire | 1 | 0 | 0.125 | 3
 | Ring Crimp | 2 | 0 | 2 | 20
 | USB C to USB C | 0 | 0 | 1 | 8

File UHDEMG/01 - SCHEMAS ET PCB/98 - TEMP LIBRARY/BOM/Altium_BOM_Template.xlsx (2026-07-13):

 |  | Bill of Material
 |  | Board | Field=Project_Name |  |  |  |  | Main Designer |  | Field=Project_Designer1
 |  | Project | Field=Project_Global |  |  |  |  | Project Date |  | Field=Project_Date
 |  | Group | Field=Project_Group |  |  |  |  | BOM Date |  | Field=ReportDate
 |  | Revision | Field=Project_Revision |  |  |  |  | Time |  | Field=ReportTime
 |  | Board Quantity | 1
Item Number | Column=Designator | Column=Description | Column=Value | Column=Manufacturer #1 | Column=Part Number #1 | Column=Supplier 1 | Column=Supplier Part Number 1 | Column=Package | Column=Assembly Type | Column=Polarized | Column=Assembly Note | Column=Quantity | Quantity Total | Column=VerifiedBy | Column=Note
 |  |  |  |  |  |  |  |  |  |  |  |  | 0
 |  |  |  |  |  |  |  |  |  |  |  |  | 0
 |  |  |  |  |  |  |  |  |  |  |  |  | 0
Other Comments or Special Instructions

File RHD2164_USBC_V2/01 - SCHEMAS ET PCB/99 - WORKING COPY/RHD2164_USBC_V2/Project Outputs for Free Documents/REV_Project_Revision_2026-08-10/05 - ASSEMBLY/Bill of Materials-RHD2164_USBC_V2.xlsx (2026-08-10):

Assembly Note | Assembly Type | Description | Designator | Magnetic Material | Manufacturer #1 | Note | Package | Part Number #1 | Polarized | Quantity | Supplier 1 | Supplier Part Number 1 | Value | VerifiedBy
 |  | Capacitor | C1, C2 |  |  |  |  |  |  | 2
 |  | 36 Position FPC Connector Contacts, Bottom 0.020" (0.50mm) Surface Mount, Right Angle | J1, J2 |  |  |  |  |  |  | 2
 |  | USB-C (USB TYPE-C) USB 3.2 Gen 1 (USB 3.1 Gen 1, Superspeed (USB 3.0)) Receptacle Connector 24 Position Through Hole, Right Angle | J3 |  |  |  |  |  |  | 1
 |  | Resistor | R1, R2, R3, R4 |  |  |  |  |  |  | 4
 |  |  | TP1, TP2, U1 |  |  |  | [NoParam], BGA104_9X7 |  |  | 3

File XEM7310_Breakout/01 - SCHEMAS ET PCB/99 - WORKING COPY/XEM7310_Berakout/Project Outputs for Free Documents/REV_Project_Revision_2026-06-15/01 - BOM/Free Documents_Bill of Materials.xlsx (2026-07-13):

Assembly Note | Assembly Type | Description | Designator | Magnetic Material | Manufacturer #1 | Note | Package | Part Number #1 | Polarized | Quantity | Supplier 1 | Supplier Part Number 1 | Value | VerifiedBy
 |  | CAP CER 0.1UF 50V X7R 0603 | C1_A, C1_B, C1_C, C1_D, C1_E, C1_F, C1_G, C1_H, C3_A, C3_B, C3_C, C3_D, C3_E, C3_F, C3_G, C3_H, C6, C9 |  |  |  | CC0603-DA |  |  | 18 |  |  | 100 nF
 |  | Cap Ceramic 1nF 50V X7R ±10% Pad SMD 0603 +125°C T/R | C2_A, C2_B, C2_C, C2_D, C2_E, C2_F, C2_G, C2_H |  |  |  |  |  |  | 8
 |  | Chip Multilayer Ceramic Capacitors for General Purpose, 0603, 10uF, X7R, 15%, 10%, 10V | C4_A, C4_B, C4_C, C4_D, C4_E, C4_F, C4_G, C4_H, C5 |  |  |  |  |  |  | 9
 |  | Chip Multilayer Ceramic Capacitors for General Purpose, 0805, 22uF, X6S, 22%, 20%, 16V | C7 |  |  |  |  |  |  | 1
 |  | CAP CER 1UF 16V X7R 0603 | C8 |  |  |  | CC0603-DA |  |  | 1 |  |  | 1 uF
 |  | USB-C (USB TYPE-C) USB 3.2 Gen 1 (USB 3.1 Gen 1, Superspeed (USB 3.0)) Receptacle Connector 24 Position Through Hole, Right Angle | J1_A, J1_B, J1_C, J1_D, J1_E, J1_F, J1_G, J1_H |  |  |  |  |  |  | 8
 |  | 80 Position Connector Header, Outer Shroud Contacts Surface Mount Gold | J2, J7 |  |  |  | None |  |  | 2
 |  | 40 Position Receptacle Connector 0.100" (2.54mm) Through Hole Gold | J3, J4, J5, J6 |  |  |  | None |  |  | 4
 |  | Connector Header Through Hole 2 position 0.100" (2.54mm) | J8 |  |  |  |  |  |  | 1
 |  | 0.025" SQ Post Header, Through-hole, Vertical, -55 to 125 degC, 2.54 mm Pitch, 3-Pin, Male, RoHS | J9 |  |  |  |  |  |  | 1
 |  | Power Barrel Connector Jack 2.00mm ID (0.079"), 5.50mm OD (0.217") Through Hole, Right Angle | J10 |  |  |  | None |  |  | 1
 |  | RES SMD 0 OHM JUMPER 1/10W 0603 | R2 |  |  |  | RC0603 |  |  | 1 |  |  | 0Ω
 |  | RES 10K OHM 1% 1/10W 0603 | R3, R4, R5, R6 |  |  |  |  |  |  | 4
 |  | Dip Switch SPST 4 Position Surface Mount Slide (Standard) Actuator 25mA 24VDC | S1 |  |  |  | None |  |  | 1
 |  | IC TRANSCEIVER HALF 4/1 20TSSOP | U1_A, U1_B, U1_C, U1_D, U1_E, U1_F, U1_G, U1_H |  |  |  |  |  |  | 8

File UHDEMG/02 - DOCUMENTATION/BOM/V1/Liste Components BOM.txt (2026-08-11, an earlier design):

RHD2164 USBC:
- 1x USBC: 217183-0001
- 1x INTAN: RHD2164
- 2x ZIF: 3-2492104-6
- 3x 100R Resistor 0402
- 1x 0R00 Resistor 0402
- 1x 100nF Capacitor 0402
- 1x 10nF Capacitor 0402

Electrode Breakout:
- 2x ZIF: 3-2492104-6
- 4x Header 2x8

FPGA Breakout:
- 8x USBC: 217183-0001
- 8x LVDS Driver: SN65LVDT41PW

- 4x Header 2x20
- 2x FPGA Connector: BTE-040-01-F-D-AD

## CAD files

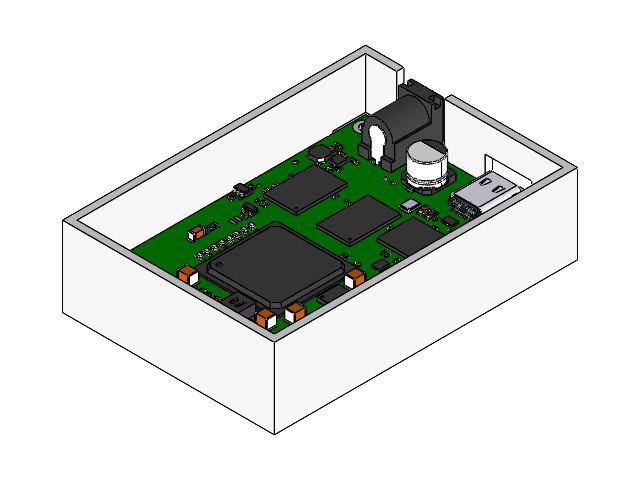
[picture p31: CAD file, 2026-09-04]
UHDEMG/06 - MECHANICAL/01 - IMPORTS/XEM7310/XEM7310.SLDASM
PCB.STEP
C1.STEP x 80
C2_0201.STEP x 85
C18.STEP x 7
C69.STEP x 14
C75.STEP x 12
C84.STEP
C171.STEP x 4
D1.STEP x 10
D11.STEP x 2
F1.STEP
FB1.STEP x 8
FB7.STEP x 2
J1.STEP
J2.STEP
L1.STEP
L2.STEP x 3
MC1.STEP x 2
R1.STEP x 95
R61.STEP x 2
U1.STEP
U2.STEP
U3.STEP
U4.STEP
U5.STEP
U6.STEP
U7.STEP
U8.STEP x 2
U9.STEP
U11.STEP x 2
U13.STEP
U15.STEP
U16.STEP x 3
U17.STEP
U20.STEP
U21___.STEP
U22.STEP x 2
FPGA_Dev_Kit_Bracket

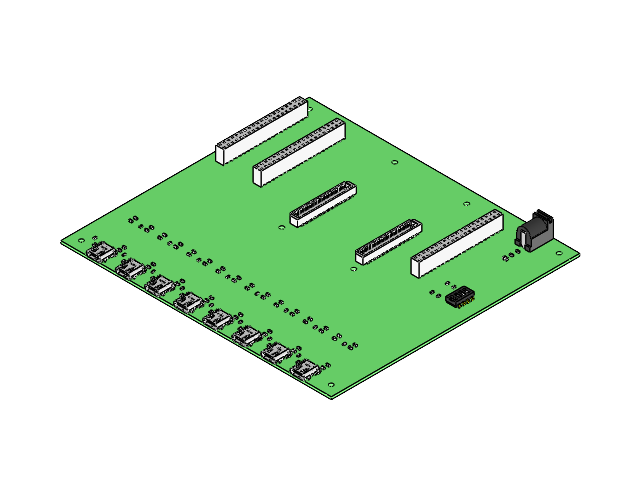
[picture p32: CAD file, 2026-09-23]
UHDEMG/06 - MECHANICAL/04 - ASSEMBLY/UHDEMG_FPGA_DB.SLDASM
Extruded.step x 56
Extruded-0.step x 28
6724678480.step
shield.step x 8
body.step x 8
terminal.step x 8
mating terminal.step x 8
logo.step x 8
6724678320.step
BTE-040-01-D-A_terminal.step x 2
T-1S39-040-01-F.step x 2
T-1S39-040-01-F-2.step x 2
T1SSW-120-01-F-D.step x 3
P2SSW-120-01-F-D.step x 3
Extruded-1.step x 100
Extruded-2.step x 50
Extruded-3.step x 2
Extruded-4.step
UHDEMG_FPGA_DB_Board

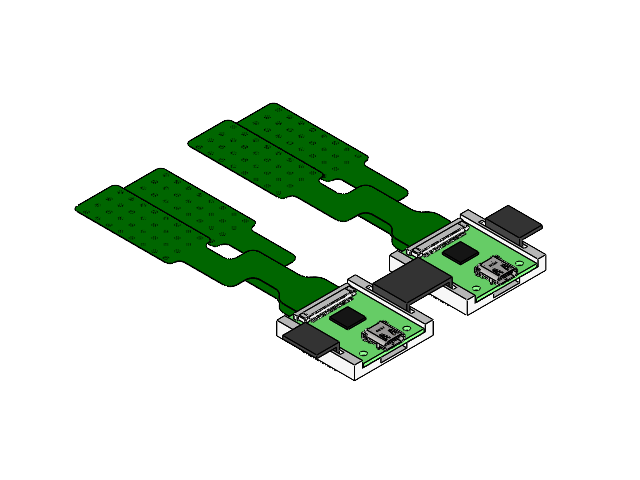
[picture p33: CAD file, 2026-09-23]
UHDEMG/06 - MECHANICAL/04 - ASSEMBLY/UHDEMG_Arm_Setup.SLDASM
UHDEMG_RHD2132_CASE x 2
shield.step x 2
body.step x 2
terminal.step x 2
mating terminal_1.step x 2
logo_1.step x 2
QFN_8x8mm_1.step x 4
c-3-2492104-6-1-3d_1.step x 4
UHDEMG_RHD2132_Board x 2
UHDEMG_Strap
Microneedle_3D.step x 64
Microneedle_3D_3.step x 64

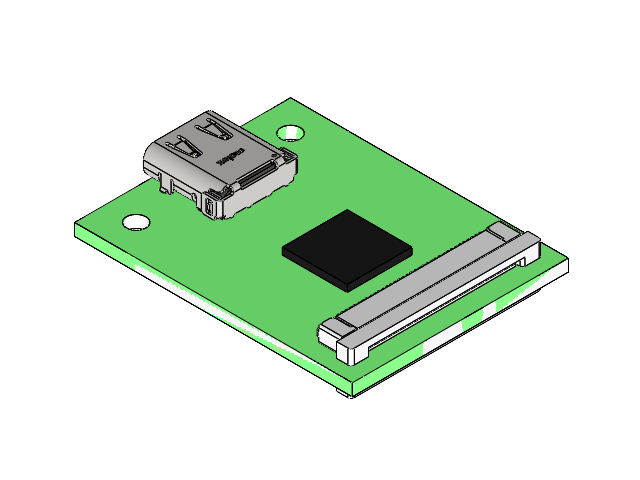
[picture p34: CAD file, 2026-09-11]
UHDEMG/06 - MECHANICAL/04 - ASSEMBLY/RHD2132_64CH.SLDASM
shield.step
body.step
terminal.step
mating terminal_1.step
logo_1.step
QFN_8x8mm_1.step x 2
c-3-2492104-6-1-3d_1.step x 2
UHDEMG_RHD2132_Board

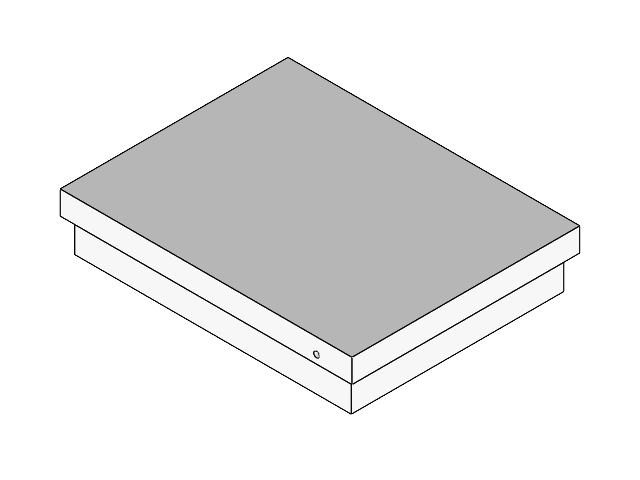
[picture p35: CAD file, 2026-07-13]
XEM7310_Breakout/06 - MECHANICAL/Breakout_Case.SLDASM
Breakout_Case_Bottom
Breakout_Case_Top

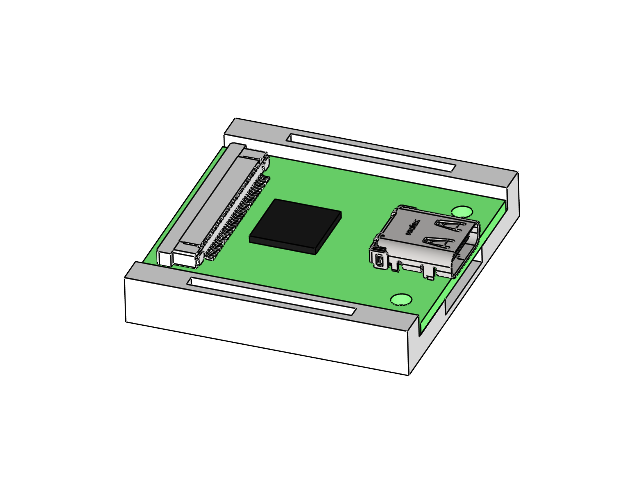
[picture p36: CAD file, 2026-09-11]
UHDEMG/06 - MECHANICAL/04 - ASSEMBLY/UHDEMG_RHD2132_Case.SLDASM
UHDEMG_RHD2132_CASE
shield.step
body.step
terminal.step
mating terminal_1.step
logo_1.step
QFN_8x8mm_1.step x 2
c-3-2492104-6-1-3d_1.step x 2
UHDEMG_RHD2132_Board

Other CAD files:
UHDEMG/06 - MECHANICAL/02 - EXPORTS/E30_2.step.SLDASM
UHDEMG/06 - MECHANICAL/02 - EXPORTS/E2_1.step.SLDASM
UHDEMG/06 - MECHANICAL/02 - EXPORTS/E29_1.step.SLDASM
UHDEMG/06 - MECHANICAL/02 - EXPORTS/E15_2.step.SLDASM
UHDEMG/06 - MECHANICAL/02 - EXPORTS/E7_2.step.SLDASM
UHDEMG/06 - MECHANICAL/02 - EXPORTS/E12_2.step.SLDASM
UHDEMG/06 - MECHANICAL/02 - EXPORTS/E22_2.step.SLDASM
UHDEMG/06 - MECHANICAL/02 - EXPORTS/E28_2.step.SLDASM
UHDEMG/06 - MECHANICAL/02 - EXPORTS/E9_1.step.SLDASM
UHDEMG/06 - MECHANICAL/02 - EXPORTS/E12_1.step.SLDASM
UHDEMG/06 - MECHANICAL/02 - EXPORTS/E27_2.step.SLDASM
UHDEMG/06 - MECHANICAL/02 - EXPORTS/E10_2.step.SLDASM
Archive/Microneedle_Patch/02 - DOCUMENTATION/Microneedle_3D.STEP
Archive/Microneedle_Patch/02 - DOCUMENTATION/UNeedle_Patch_Dimensions.DXF
Archive/Microneedle_Patch/02 - DOCUMENTATION/UNeedle_Patch_Dimensions.SLDPRT
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

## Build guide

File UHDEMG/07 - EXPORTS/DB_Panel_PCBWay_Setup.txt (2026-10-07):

Breakout Boards Panel:
Board Type: Panel by customer
X-out allowance in panel: Accept
Different design in panel: 2
Size: 241.5 mm X 206 mm
Quantity: 5 pcs
Layers: 4 Layers
Material: FR-4
FR4-TG: S1000H TG150
Thickness: 1.6 mm
Min track/spacing: 6/6 mil
Min hole size: 0.2 mm
Solder mask: Green
Silkscreen: White
UV printing multi-color: None
Edge Connector: No
Surface finish: Immersion gold (ENIG)
Thickness of Immersion Gold: 1U"
Via process: Tented Vias
Finished Copper: 1 oz Cu
Inner Copper: 1 oz
Remove product info: Yes

SMD-Stencil:
Stencil Type: Non-framework
Multi-level/Step stencil: No
Size (mm): Custom Size (Valid Area 550 x 550 mm)
Stencil side: Top
Quantity: 1 piece
Thickness: 0.10 mm
Existing fiducials: No
Electropolishing: Yes

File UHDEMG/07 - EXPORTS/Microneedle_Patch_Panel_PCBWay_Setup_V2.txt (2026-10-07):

Microneedle Patch Panel:
PCB Type: Flexible PCB
Board Type: Panel by customer
X-out allowance in panel: Accept

Different design in panel: 2
Size: 131.95 mm X 214.4 mm
Quantity: 5 pcs
Layers: 2 Layers

Material: Polymide Flex
Thickness: 0.18 mm
Min track/spacing: 0.06 mm
Min hole size: 0.15/0.35 mm
Solder mask: Yellow coverlay
Silkscreen: White
Edge Connector: Yes
Stiffener Both sides
TOP PI and BOT PI: 0.125 mm
Surface finish: ENEPIG
Thickness of ENEPIG: Ni: 200 U" Pd: 4 U" Au: 4 U"
Finished Copper: 0.5 oz Cu (18 um)
E-Test: 100%
3M/Tesa tape: without
Conductive double sided tape: without
EMI Shielding film: without

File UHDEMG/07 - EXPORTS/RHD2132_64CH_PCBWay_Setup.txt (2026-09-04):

RHD2132_64CH:
Board Type: Single pieces
Different design in panel: 1
Size: 26.7 mm X 34.3 mm
Quantity: 10 pcs
Layers: 6 Layers
Material: FR-4
FR4-TG: S1000H TG150
Thickness: 1.6 mm
Min track/spacing: 4/4 mil
Min hole size: 0.2 mm
Solder mask: Green
Silkscreen: White
UV printing multi-color: None
Edge Connector: No
Surface finish: Immersion gold (ENIG)
Thickness of Immersion Gold: 1U"
Via process: Tenting Vias
Finished Copper: 1 oz Cu
Inner Copper: 1 oz
Remove product info: Yes

SMD-Stencil:
Stencil Type: Non-framework
Multi-level/Step stencil: No
Size (mm): Custom Size (Valid Area 190 x 290 mm)
Stencil Side: Top + Bottom (On single stencil)
Quantity: 1 piece
Thickness: 0.10 mm
Existing fiducials: No
Electropolishing: Yes

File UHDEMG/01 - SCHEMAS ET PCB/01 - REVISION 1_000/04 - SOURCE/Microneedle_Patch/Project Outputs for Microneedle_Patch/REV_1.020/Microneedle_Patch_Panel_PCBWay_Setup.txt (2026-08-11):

Microneedle Patch:
PCB Type: Flexible PCB
Board Type: Panel by supplier
Different design in panel: 1

Size: 28.8 mm X 93 mm
Quantity: 16 pcs
Layers: 2 Layers

Material: Polymide Flex
Thickness: 0.18 mm
Min track/spacing: 0.06 mm
Min hole size: 0.15/0.35 mm
Solder mask: Black coverlay
Silkscreen: White
Edge Connector: Yes
Stiffener Both sides
TOP PI and BOT PI: 0.125 mm
Surface finish: ENEPIG
Thickness of ENEPIG: Ni: 200 U" Pd: 4 U" Au: 4 U"
Finished Copper: 0.5 oz Cu (18 um)
E-Test: 100%
3M/Tesa tape: without
Conductive double sided tape: without
EMI Shielding film: without

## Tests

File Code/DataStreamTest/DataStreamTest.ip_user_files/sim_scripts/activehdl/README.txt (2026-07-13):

################################################################################
# Vivado (TM) v2025.2 (64-bit)
#
# README.txt: Please read the sections below to understand the steps required to
#             run the exported script and how to fetch design source file details
#             from the file_info.txt file.
#
# Generated by export_simulation on Mon Jun 15 15:18:48 -0400 2026
#
################################################################################

1. Steps to run the generated simulation script

From the shell prompt in the current directory, issue the following command:-

./main.sh

This command will launch the 'compile', 'elaborate' and 'simulate' functions
implemented in the script file for the 3-step flow. These functions are called
from the main 'run' function in the script file.

The 'run' function first calls the 'check_args' function, the purpose of which
is to verify the generated script arguments and print error if incorrect switch
is specified. The 'run' function then calls the 'setup' function, the purpose of
which is to specify custom or initialization commands. The function also executes
following sub-functions:-
'reset_run' if -reset_run switch is specified.
'reset_log' if -reset_log switch is specified.

The purpose of 'reset_run' function' is to delete the simulator generated design
data from the previous run and the purpose of 'reset_log' function' is to delete
the simulator generated log files.

The 'run' function then calls the 'init_lib' function, the purpose of which is to
create design library mappings and directories. This function is called before the
'compile' step. By default, if '-step' switch is specified with the script then the
script will execute that specfic step, else it will execute all steps applicable
for the target simulator.

For more information on the script, please type './main.sh -help'

2. Design source file information

export_simulation generates a 'file_info.txt' file that contains design file information
based on the compile order when export_simulation was executed from Vivado. The file
contains information about the file name, type, library it is compiled into, whether
it is part of the IP, associated library, file path information in a comma separated
format. This file can be parsed to extract the required information for generating a
custom script or can be read from verification test infra.

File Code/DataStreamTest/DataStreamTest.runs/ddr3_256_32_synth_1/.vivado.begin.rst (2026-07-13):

<?xml version="1.0"?>
<ProcessHandle Version="1" Minor="0">
    <Process Command="vivado.bat" Owner="olivi" Host="LAPTOP-H85DCTKA" Pid="26228" HostCore="20" HostMemory="034049220608">
    </Process>
</ProcessHandle>

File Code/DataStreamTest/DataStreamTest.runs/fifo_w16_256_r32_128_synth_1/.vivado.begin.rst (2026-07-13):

<?xml version="1.0"?>
<ProcessHandle Version="1" Minor="0">
    <Process Command="vivado.bat" Owner="olivi" Host="LAPTOP-H85DCTKA" Pid="17996" HostCore="20" HostMemory="034049220608">
    </Process>
</ProcessHandle>

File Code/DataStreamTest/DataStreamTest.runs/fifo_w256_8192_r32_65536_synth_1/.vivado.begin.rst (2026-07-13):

<?xml version="1.0"?>
<ProcessHandle Version="1" Minor="0">
    <Process Command="vivado.bat" Owner="olivi" Host="LAPTOP-H85DCTKA" Pid="17308" HostCore="20" HostMemory="034049220608">
    </Process>
</ProcessHandle>

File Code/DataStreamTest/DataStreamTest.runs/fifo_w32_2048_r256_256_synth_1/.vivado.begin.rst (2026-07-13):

<?xml version="1.0"?>
<ProcessHandle Version="1" Minor="0">
    <Process Command="vivado.bat" Owner="olivi" Host="LAPTOP-H85DCTKA" Pid="18352" HostCore="20" HostMemory="034049220608">
    </Process>
</ProcessHandle>

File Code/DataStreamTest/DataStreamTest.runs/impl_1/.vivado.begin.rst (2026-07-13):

<?xml version="1.0"?>
<ProcessHandle Version="1" Minor="0">
    <Process Command="vivado.bat" Owner="olivi" Host="LAPTOP-H85DCTKA" Pid="12960" HostCore="20" HostMemory="034049220608">
    </Process>
</ProcessHandle>
<?xml version="1.0"?>
<ProcessHandle Version="1" Minor="0">
    <Process Command="vivado.bat" Owner="olivi" Host="LAPTOP-H85DCTKA" Pid="24156" HostCore="20" HostMemory="034049220608">
    </Process>
</ProcessHandle>

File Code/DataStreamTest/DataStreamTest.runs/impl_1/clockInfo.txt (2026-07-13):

-------------------------------------
| Tool Version : Vivado v.2025.2
| Date         : Mon Jun 15 15:22:53 2026
| Host         : LAPTOP-H85DCTKA
| Design       : design_1
| Device       : xc7a75t-fgg484-1--
-------------------------------------

For more information on clockInfo.txt clock routing debug file see https://support.xilinx.com/s/article/000035660?language=en_US

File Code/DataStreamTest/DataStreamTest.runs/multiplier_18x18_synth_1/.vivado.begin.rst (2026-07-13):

<?xml version="1.0"?>
<ProcessHandle Version="1" Minor="0">
    <Process Command="vivado.bat" Owner="olivi" Host="LAPTOP-H85DCTKA" Pid="25672" HostCore="20" HostMemory="034049220608">
    </Process>
</ProcessHandle>

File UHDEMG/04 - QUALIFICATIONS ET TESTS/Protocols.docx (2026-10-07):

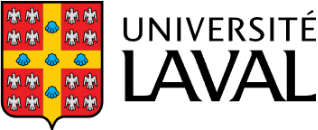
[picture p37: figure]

Liste des protocoles

Réalisé par

Olivier Bergeron

Version

1.000

Dans le cadre du cours

Maitrise en génie électrique – Avec mémoire

Directeur de recherche

Benoit Gosselin

SBioML

Faculté des sciences et de génie

Université Laval

# Révisions

Revision # | Version Date | Summary of Changes
1.000 | 2026-10-07 | Creation of the document

# Protocole #1 : Nettoyage des électrodes

## Matériel

## Analyse de risques

Index | Type de risque | Description du risque | Conséquence | Probabilité | Gravité | Niveau de risque | Mesure de prévention
1
2
3
4
5

## Éthique

## Protocole

# Protocole #2 : Application des électrodes

## Matériel

## Analyse de risques

Index | Type de risque | Description du risque | Conséquence | Probabilité | Gravité | Niveau de risque | Mesure de prévention
1
2
3
4
5

## Éthique

## Protocole

# Protocole #3 : Prise de données

## Matériel

## Analyse de risques

Index | Type de risque | Description du risque | Conséquence | Probabilité | Gravité | Niveau de risque | Mesure de prévention
1
2
3
4
5

## Éthique

## Protocole

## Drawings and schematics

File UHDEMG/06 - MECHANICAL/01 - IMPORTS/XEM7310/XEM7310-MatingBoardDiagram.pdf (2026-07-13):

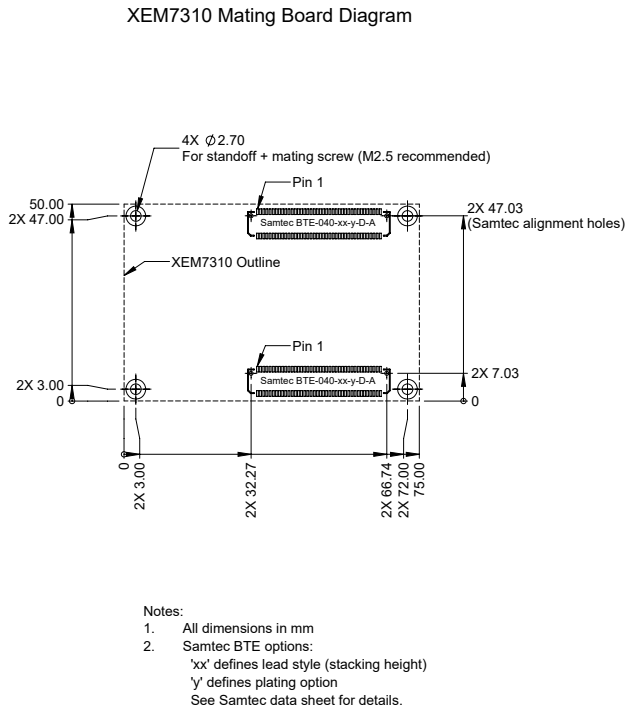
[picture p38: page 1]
XEM7310 Outline; Pin 1

XEM7310 Mating Board Diagram

For standoff + mating screw (M2.5 recommended)

(Samtec alignment holes)

Samtec BTE-040-xx-y-D-A

Notes:
1. All dimensions in mm
2. Samtec BTE options:
'xx' defines lead style (stacking height)
'y' defines plating option
See Samtec data sheet for details.

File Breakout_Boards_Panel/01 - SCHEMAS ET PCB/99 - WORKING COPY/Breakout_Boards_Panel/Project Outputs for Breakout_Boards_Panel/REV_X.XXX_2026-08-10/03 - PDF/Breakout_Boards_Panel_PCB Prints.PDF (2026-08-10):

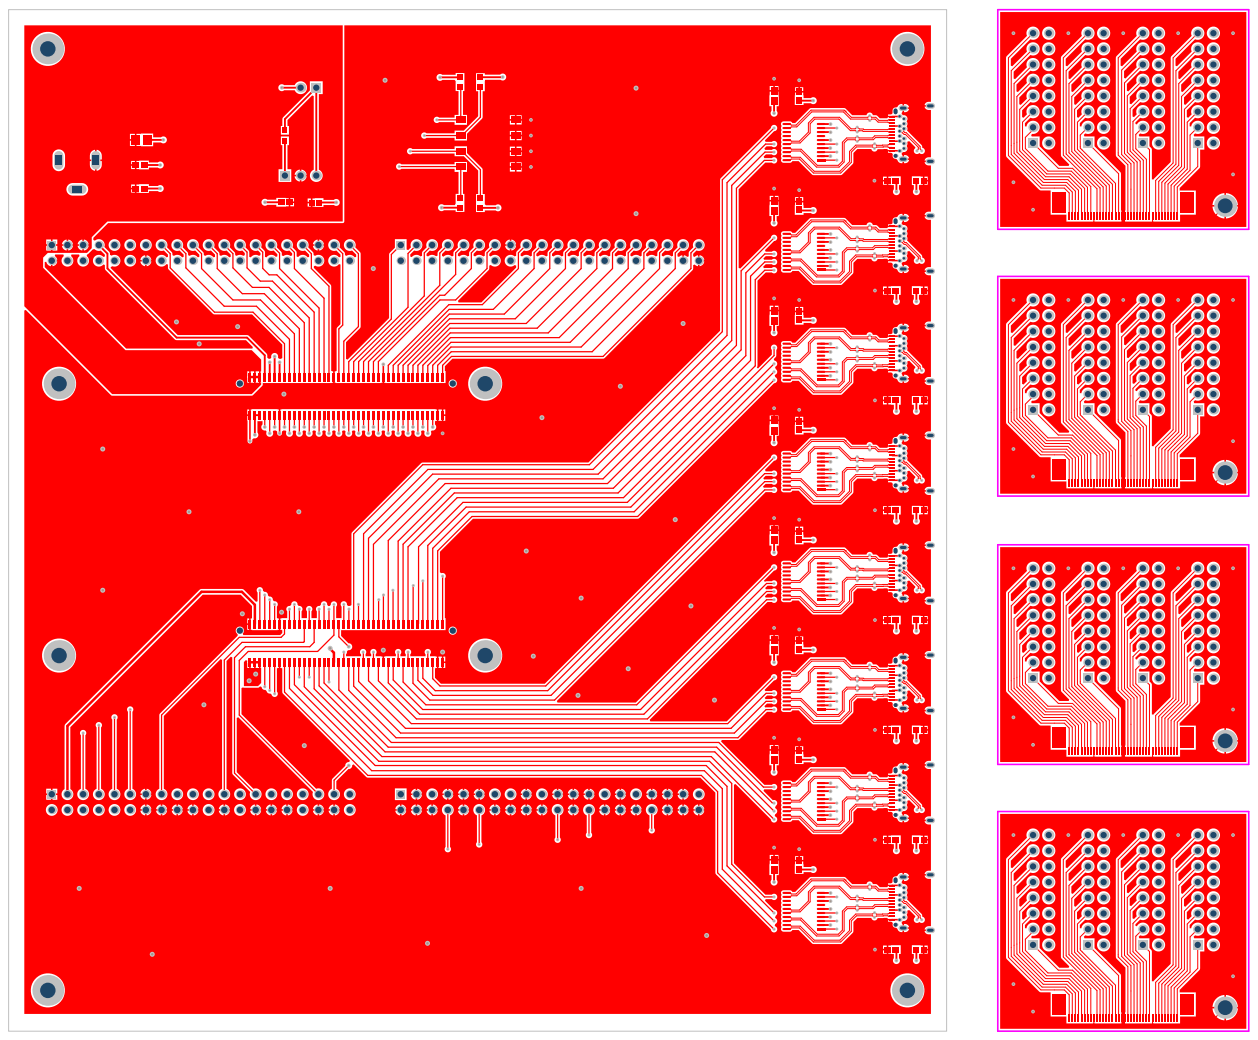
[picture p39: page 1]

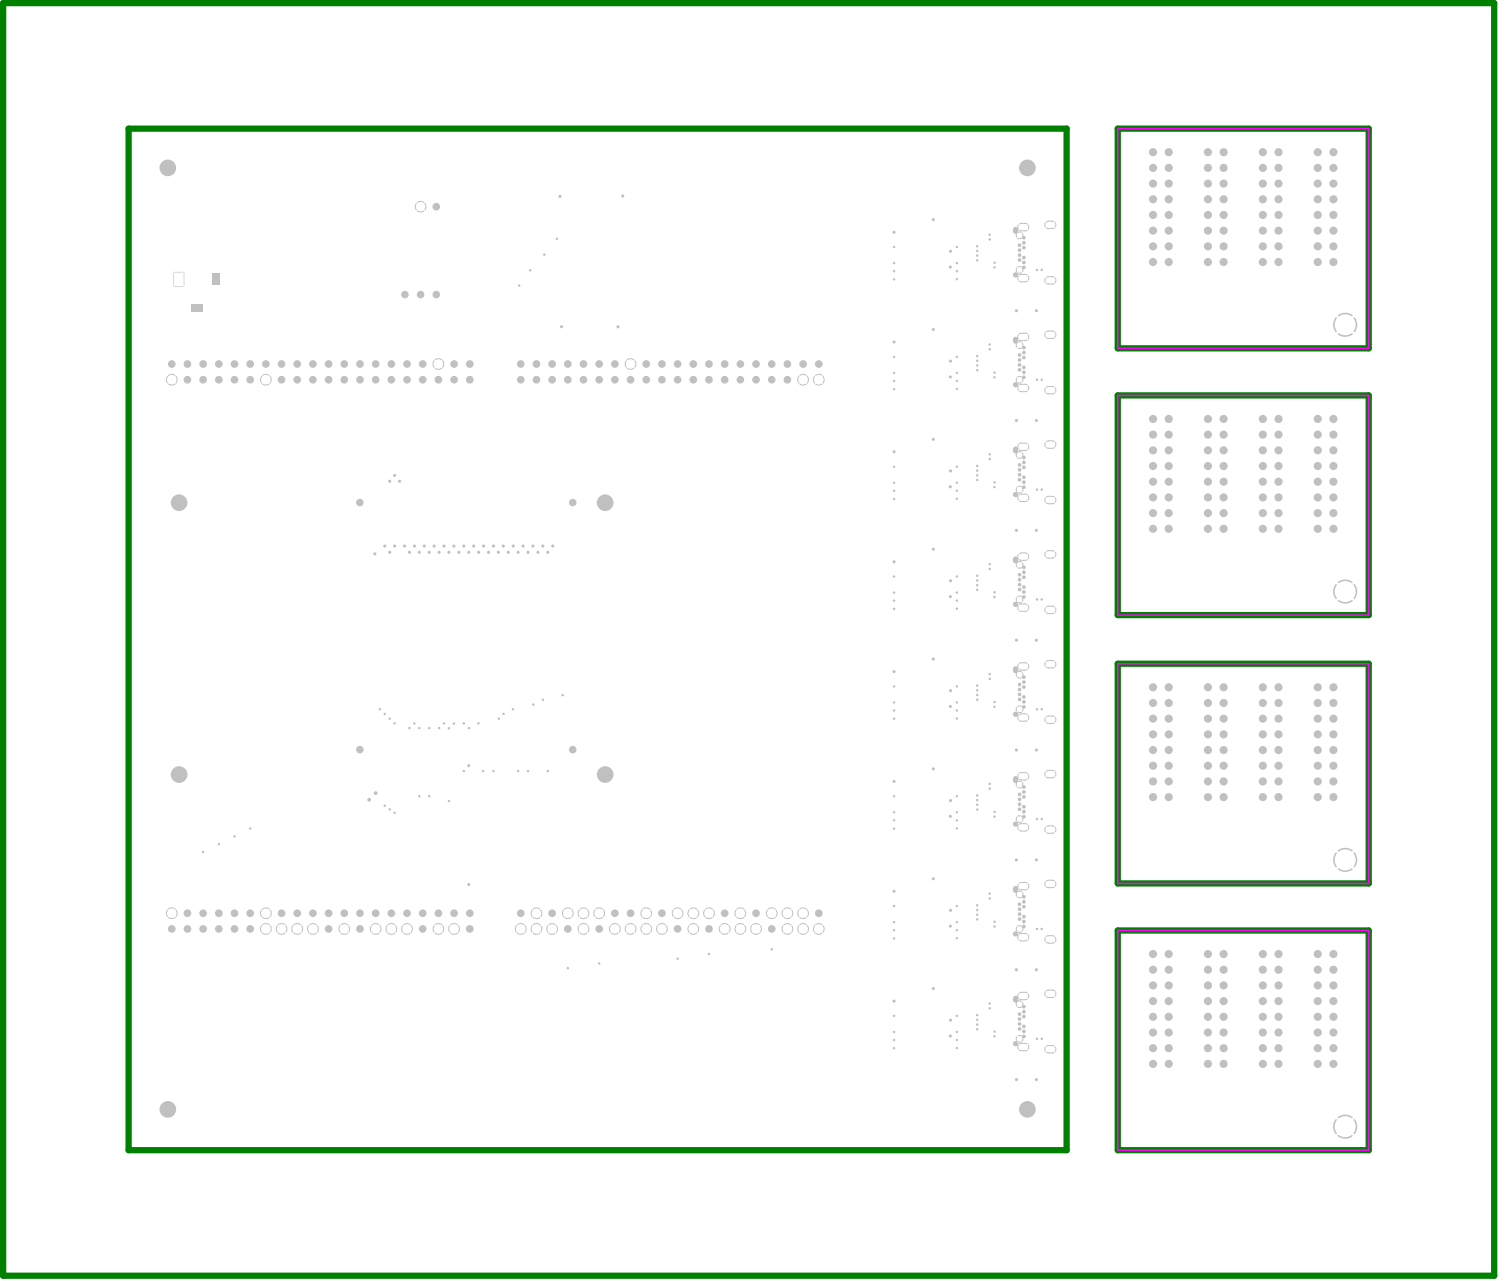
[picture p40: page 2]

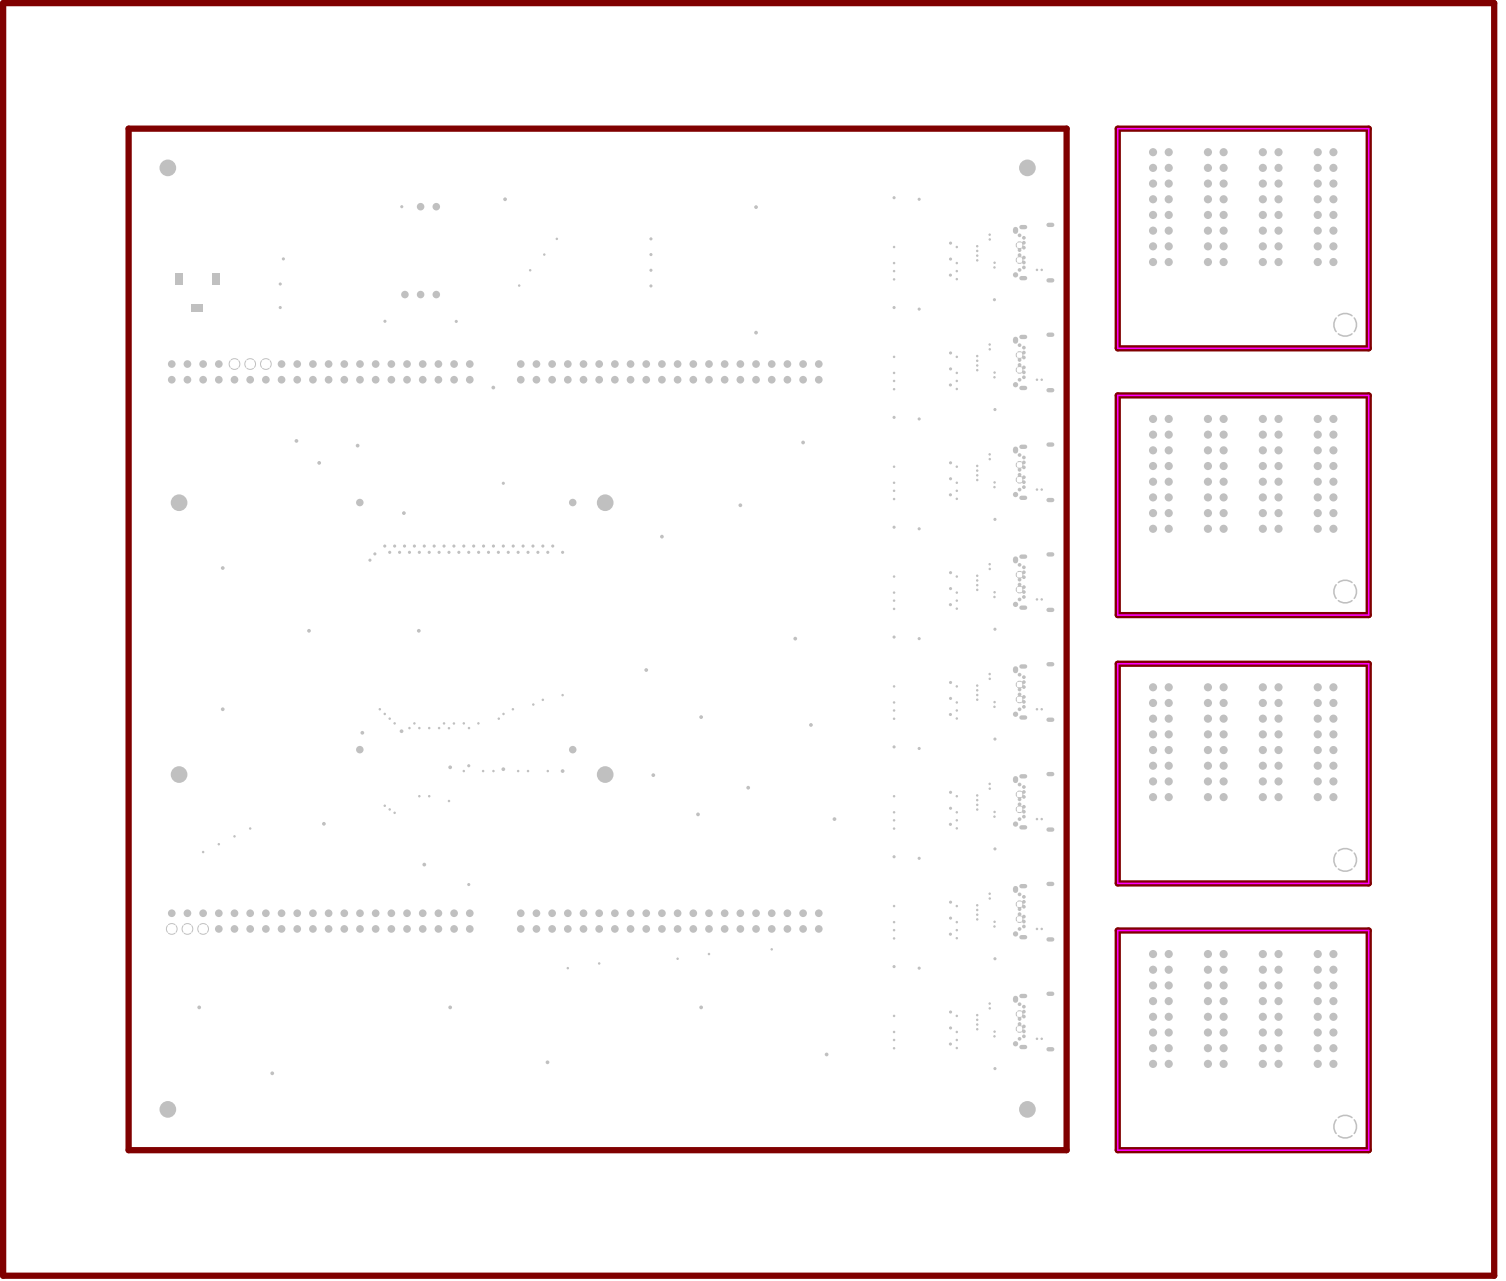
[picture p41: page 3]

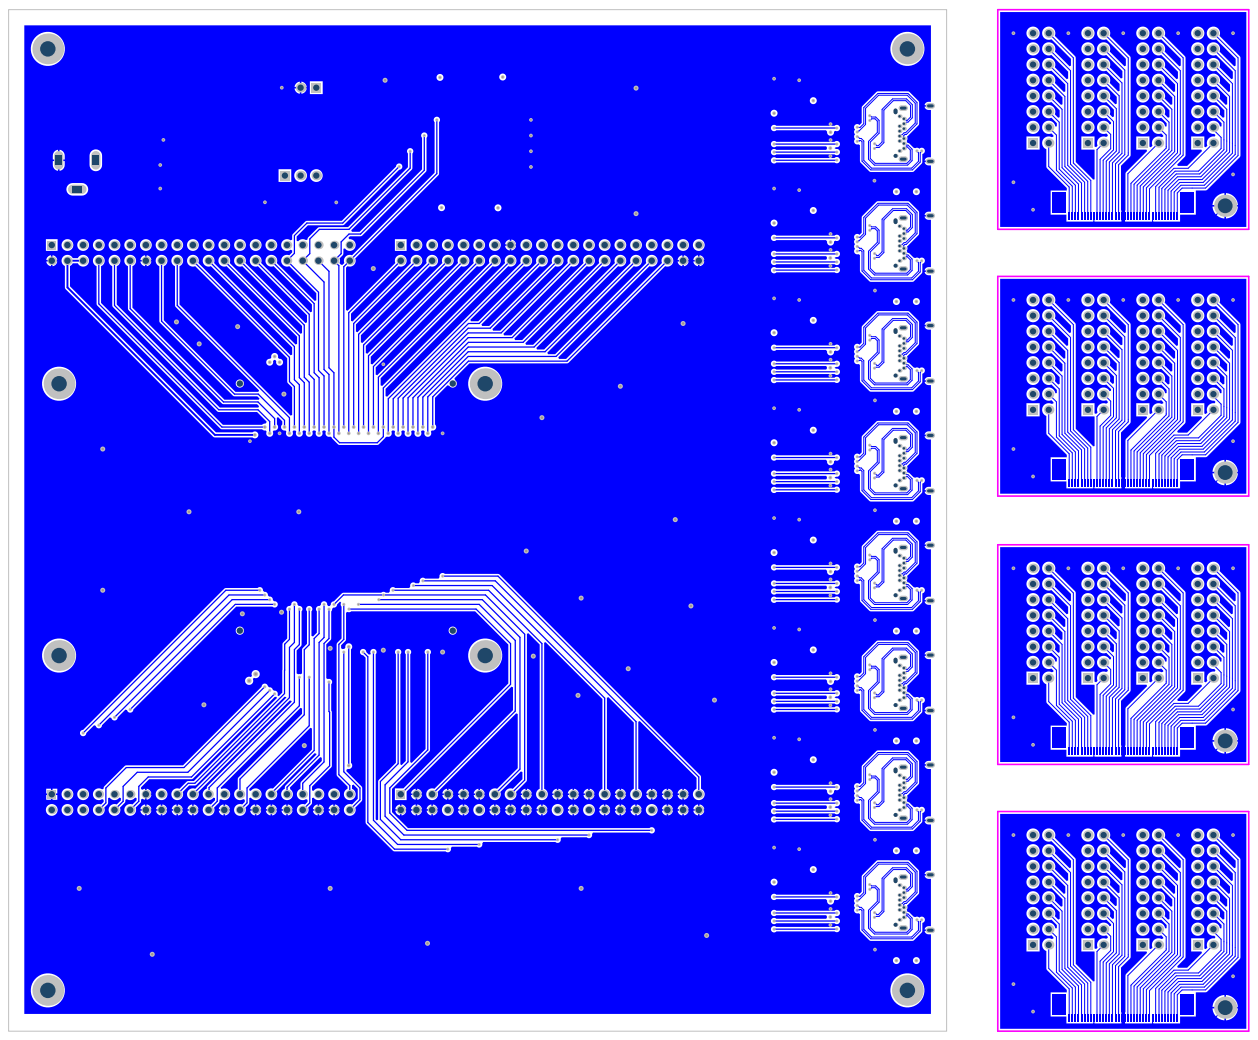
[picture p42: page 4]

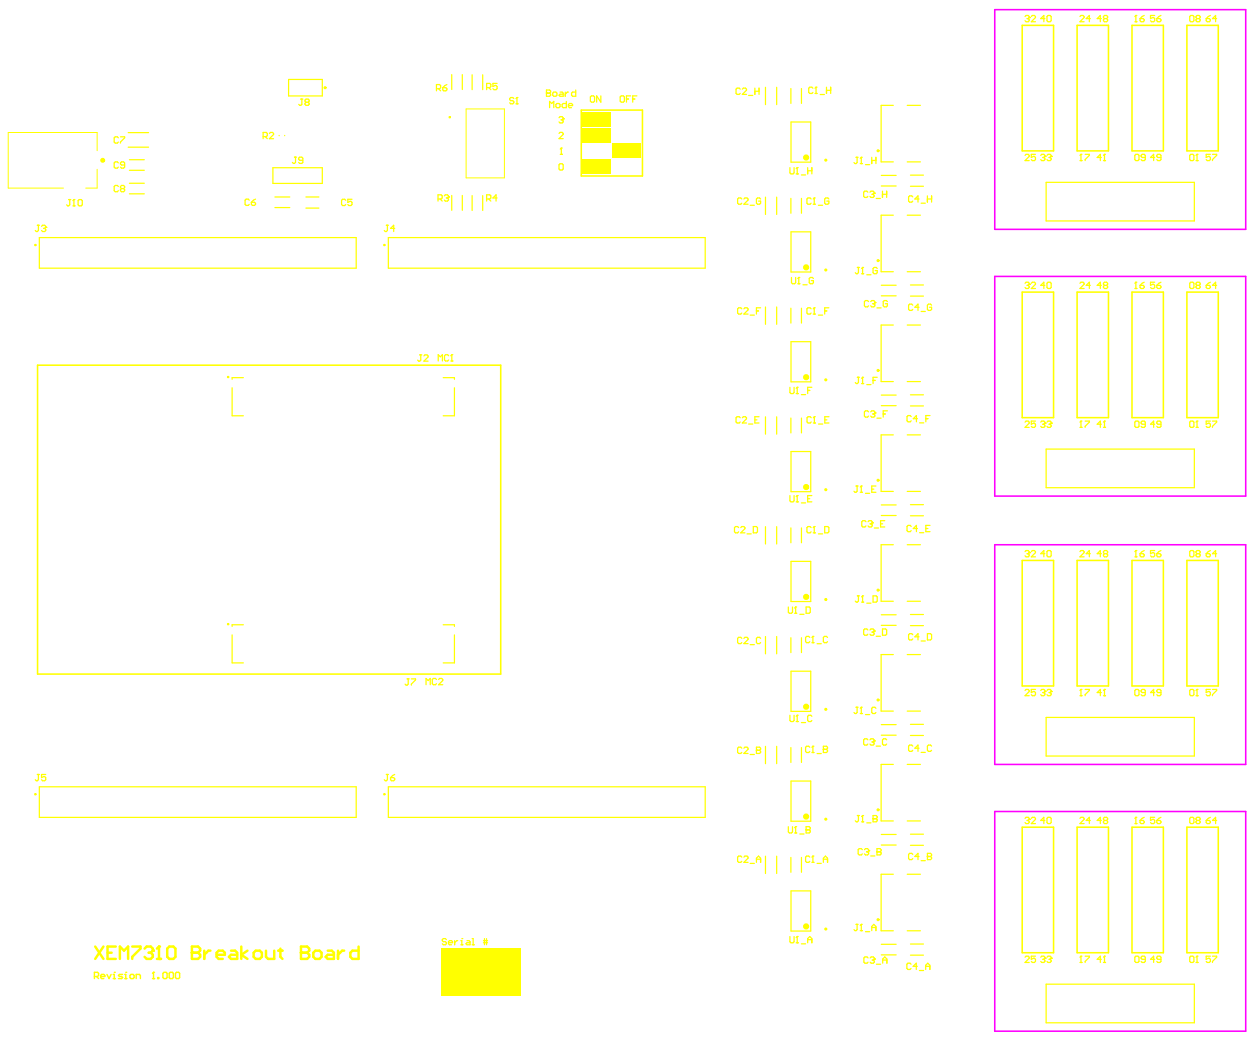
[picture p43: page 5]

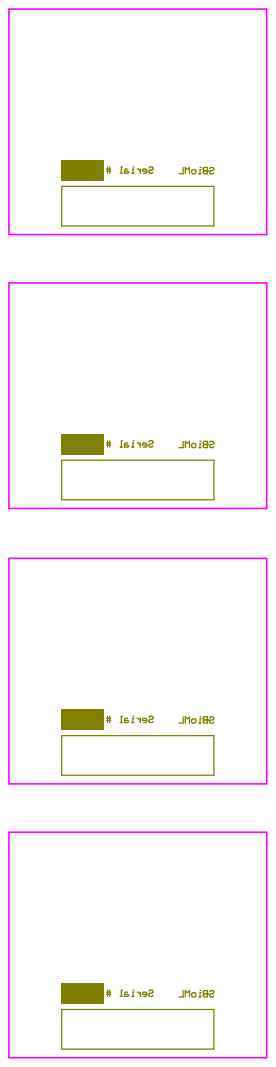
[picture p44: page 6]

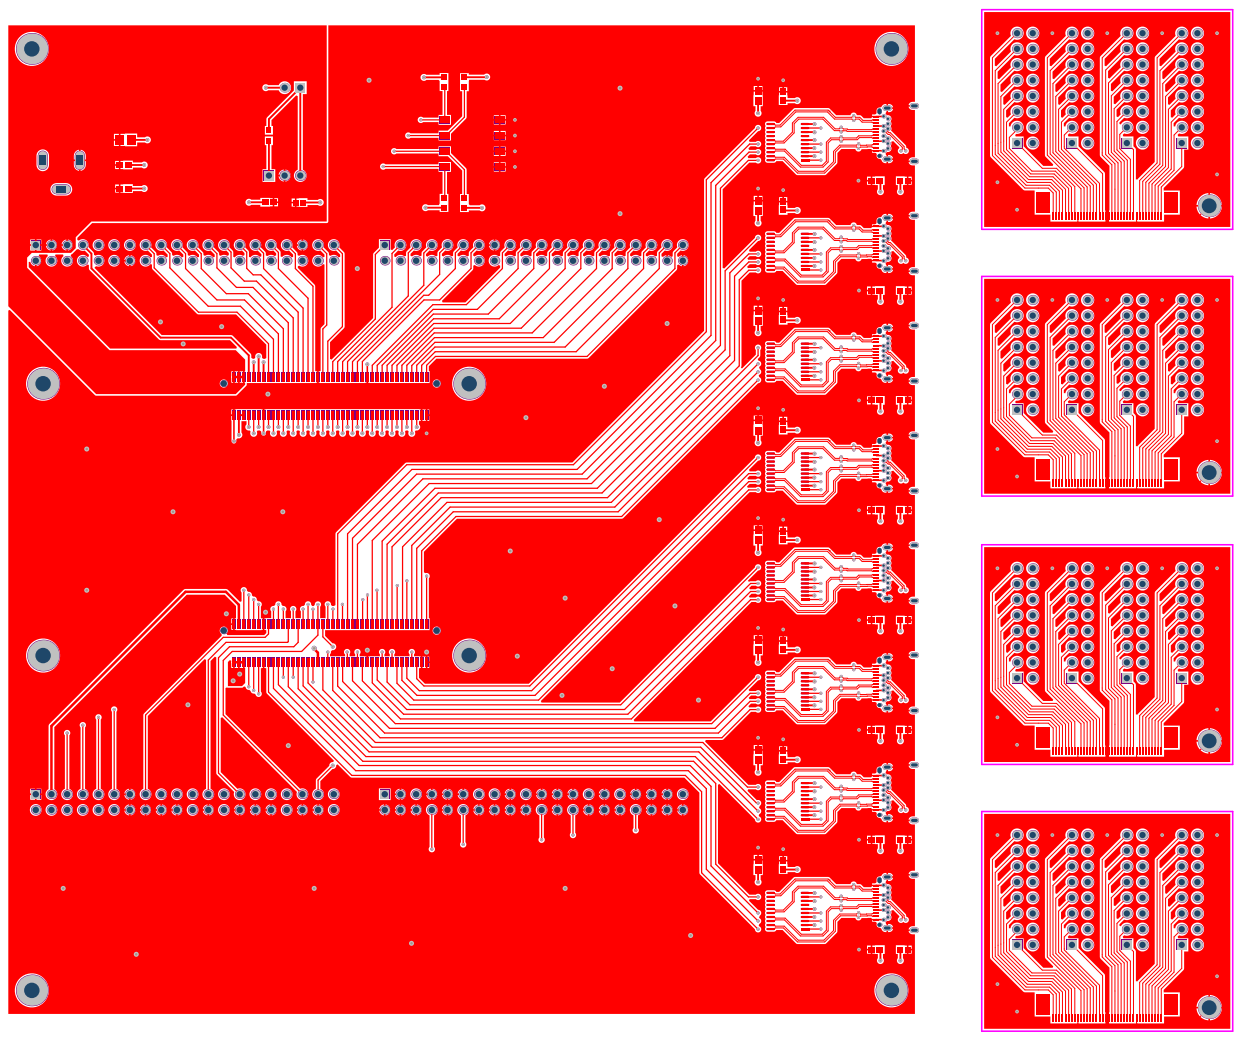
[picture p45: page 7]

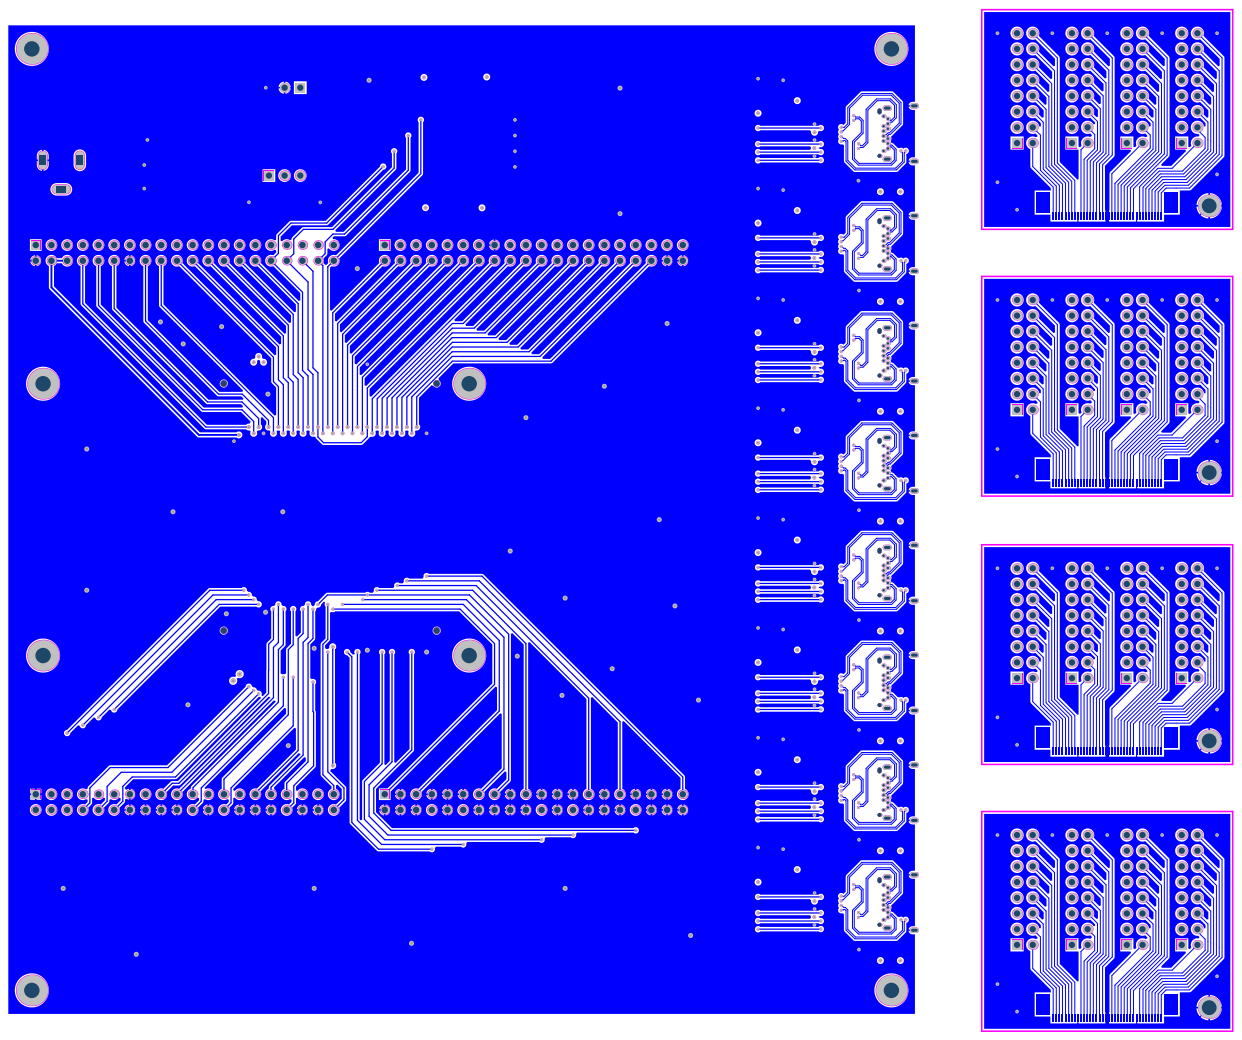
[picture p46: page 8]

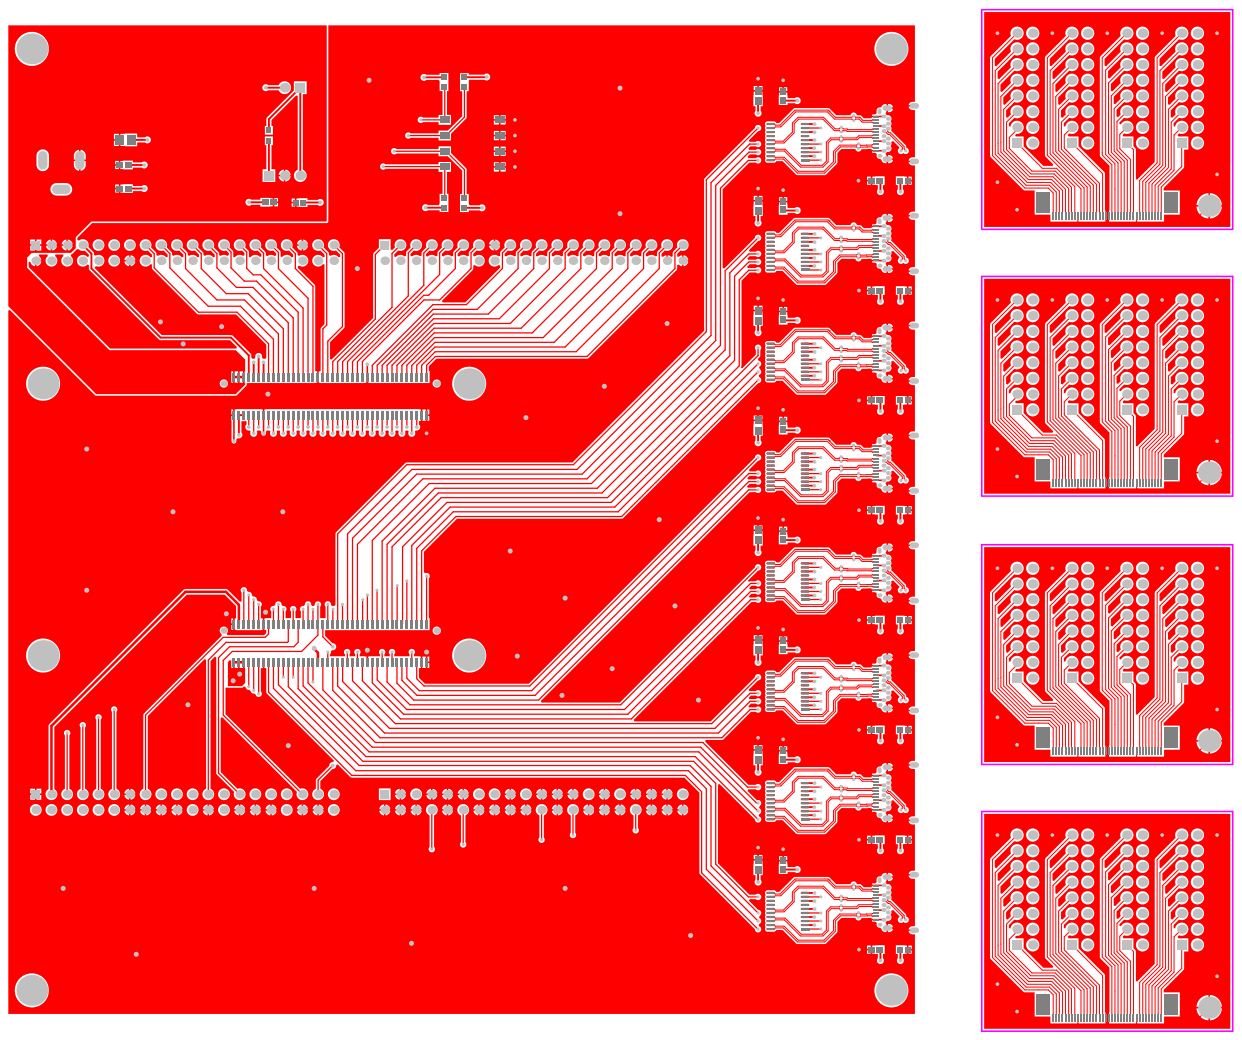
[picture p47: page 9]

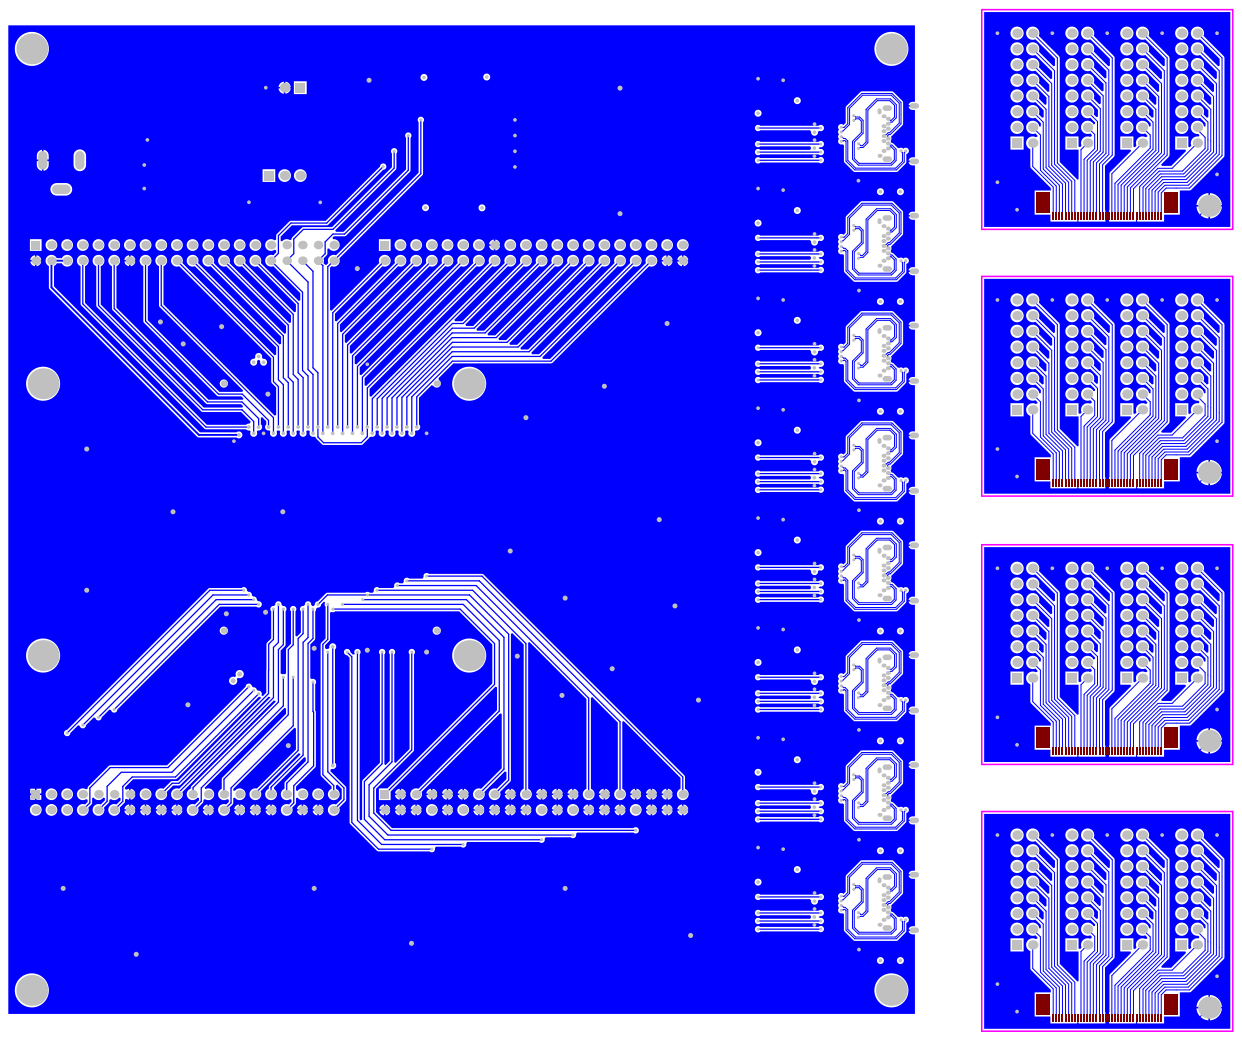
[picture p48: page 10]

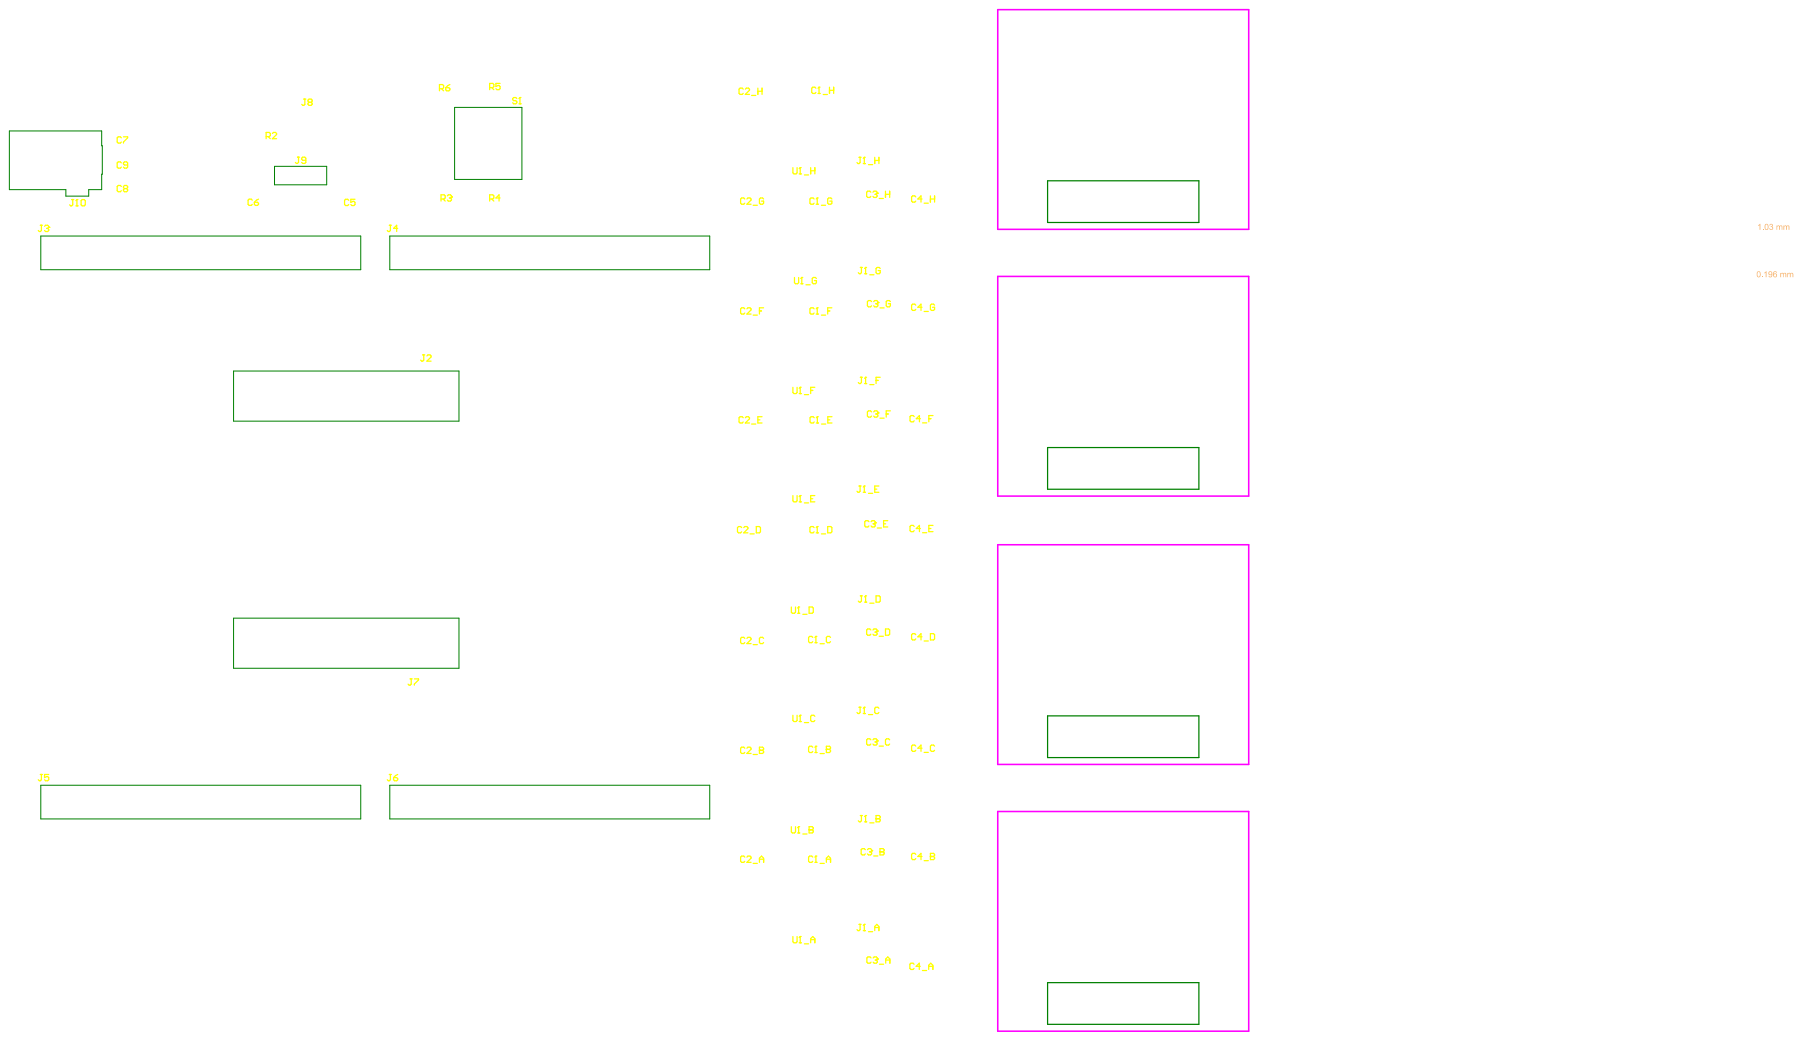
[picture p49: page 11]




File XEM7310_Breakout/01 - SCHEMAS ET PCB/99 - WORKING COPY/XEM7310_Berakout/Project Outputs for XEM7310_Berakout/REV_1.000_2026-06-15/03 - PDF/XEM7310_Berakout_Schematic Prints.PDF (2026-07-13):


Size 11x17 | Group SBioML | Revision 1.000

Date 2026-04-02 | Sheet 1 of 12

Filename Title_Page.SchDoc | Designers Olivier Bergeron


0 7 | 1 0 XAD C _V N 1 2 XAD C _V P

0 9 | 1 0 XAD C _V N
1 1 | 1 2 XAD C _V P


Siz e 11x17 | Group SBioML | R evisio n 1.000

Da te 2026-04-02 | She e t 3 of 12

Filena m e oc Onboard_IO . SchD | De sign e r s Ol i v ier Bergero n


Intan Interface Top Layer

Size 11x17 | Group SBioML | Revision 1.000

Date 2026-04-02 | Sheet 4 of 12

Intan_Interface_Top.SchDoc | Olivier Bergeron


Size 11x17 | Group SBioML | Revision 1.000

Date 2026-04-02 | Sheet 5.1 of 12

Intan_Interface.SchDoc | Olivier Bergeron


Size 11x17 | Group SBioML | Revision 1.000

Date 2026-04-02 | Sheet 5.2 of 12


Size 11x17 | Group SBioML | Revision 1.000

Date 2026-04-02 | Sheet 5.3 of 12


Size 11x17 | Group SBioML | Revision 1.000

Date 2026-04-02 | Sheet 5.4 of 12


Size 11x17 | Group SBioML | Revision 1.000

Date 2026-04-02 | Sheet 5.5 of 12


Size 11x17 | Group SBioML | Revision 1.000

Date 2026-04-02 | Sheet 5.6 of 12


Size 11x17 | Group SBioML | Revision 1.000

Date 2026-04-02 | Sheet 5.7 of 12


1 0

Siz e 11x17 | Group SBioML | R evisio n 1.000

Da te 2026-04-02 | She e t 5.8 of 12

Filena m e oc Intan_Interface. Sc h D | De sign e r s Ol i v ier Bergero n

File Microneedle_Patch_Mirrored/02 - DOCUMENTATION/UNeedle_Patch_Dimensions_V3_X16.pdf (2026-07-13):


SOLIDWORKS Maker Product. For Personal Use Only.

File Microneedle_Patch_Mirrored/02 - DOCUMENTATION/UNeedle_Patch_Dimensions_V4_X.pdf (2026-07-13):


SOLIDWORKS Maker Product. For Personal Use Only.

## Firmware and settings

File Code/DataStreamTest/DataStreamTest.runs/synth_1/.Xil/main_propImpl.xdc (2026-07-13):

set_property SRC_FILE_INFO {cfile:{C:/Users/olivi/Documents/Universite Laval/Maitrise/DataStreamTest/xem7310.xdc} rfile:../../../xem7310.xdc id:1} [current_design]
set_property src_info {type:XDC file:1 line:18 export:INPUT save:INPUT read:READ} [current_design]
set_property PACKAGE_PIN Y19 [get_ports {okHU[0]}]
set_property src_info {type:XDC file:1 line:19 export:INPUT save:INPUT read:READ} [current_design]
set_property PACKAGE_PIN R18 [get_ports {okHU[1]}]
set_property src_info {type:XDC file:1 line:20 export:INPUT save:INPUT read:READ} [current_design]
set_property PACKAGE_PIN R16 [get_ports {okHU[2]}]
set_property src_info {type:XDC file:1 line:24 export:INPUT save:INPUT read:READ} [current_design]
set_property PACKAGE_PIN W19 [get_ports {okUH[0]}]
set_property src_info {type:XDC file:1 line:25 export:INPUT save:INPUT read:READ} [current_design]
set_property PACKAGE_PIN V18 [get_ports {okUH[1]}]
set_property src_info {type:XDC file:1 line:26 export:INPUT save:INPUT read:READ} [current_design]
set_property PACKAGE_PIN U17 [get_ports {okUH[2]}]
set_property src_info {type:XDC file:1 line:27 export:INPUT save:INPUT read:READ} [current_design]
set_property PACKAGE_PIN W17 [get_ports {okUH[3]}]
set_property src_info {type:XDC file:1 line:28 export:INPUT save:INPUT read:READ} [current_design]
set_property PACKAGE_PIN T19 [get_ports {okUH[4]}]
set_property src_info {type:XDC file:1 line:31 export:INPUT save:INPUT read:READ} [current_design]
set_property PACKAGE_PIN AB22 [get_ports {okUHU[0]}]
set_property src_info {type:XDC file:1 line:32 export:INPUT save:INPUT read:READ} [current_design]
set_property PACKAGE_PIN AB21 [get_ports {okUHU[1]}]
set_property src_info {type:XDC file:1 line:33 export:INPUT save:INPUT read:READ} [current_design]
set_property PACKAGE_PIN Y22 [get_ports {okUHU[2]}]
set_property src_info {type:XDC file:1 line:34 export:INPUT save:INPUT read:READ} [current_design]
set_property PACKAGE_PIN AA21 [get_ports {okUHU[3]}]
set_property src_info {type:XDC file:1 line:35 export:INPUT save:INPUT read:READ} [current_design]
set_property PACKAGE_PIN AA20 [get_ports {okUHU[4]}]
set_property src_info {type:XDC file:1 line:36 export:INPUT save:INPUT read:READ} [current_design]
set_property PACKAGE_PIN W22 [get_ports {okUHU[5]}]
set_property src_info {type:XDC file:1 line:37 export:INPUT save:INPUT read:READ} [current_design]
set_property PACKAGE_PIN W21 [get_ports {okUHU[6]}]
set_property src_info {type:XDC file:1 line:38 export:INPUT save:INPUT read:READ} [current_design]
set_property PACKAGE_PIN T20 [get_ports {okUHU[7]}]
set_property src_info {type:XDC file:1 line:39 export:INPUT save:INPUT read:READ} [current_design]
set_property PACKAGE_PIN R19 [get_ports {okUHU[8]}]
set_property src_info {type:XDC file:1 line:40 export:INPUT save:INPUT read:READ} [current_design]
set_property PACKAGE_PIN P19 [get_ports {okUHU[9]}]
set_property src_info {type:XDC file:1 line:41 export:INPUT save:INPUT read:READ} [current_design]
set_property PACKAGE_PIN U21 [get_ports {okUHU[10]}]
set_property src_info {type:XDC file:1 line:42 export:INPUT save:INPUT read:READ} [current_design]
set_property PACKAGE_PIN T21 [get_ports {okUHU[11]}]
set_property src_info {type:XDC file:1 line:43 export:INPUT save:INPUT read:READ} [current_design]
set_property PACKAGE_PIN R21 [get_ports {okUHU[12]}]
set_property src_info {type:XDC file:1 line:44 export:INPUT save:INPUT read:READ} [current_design]
set_property PACKAGE_PIN P21 [get_ports {okUHU[13]}]
set_property src_info {type:XDC file:1 line:45 export:INPUT save:INPUT read:READ} [current_design]
set_property PACKAGE_PIN R22 [get_ports {okUHU[14]}]
set_property src_info {type:XDC file:1 line:46 export:INPUT save:INPUT read:READ} [current_design]
set_property PACKAGE_PIN P22 [get_ports {okUHU[15]}]
set_property src_info {type:XDC file:1 line:47 export:INPUT save:INPUT read:READ} [current_design]
set_property PACKAGE_PIN R14 [get_ports {okUHU[16]}]
set_property src_info {type:XDC file:1 line:48 export:INPUT save:INPUT read:READ} [current_design]
set_property PACKAGE_PIN W20 [get_ports {okUHU[17]}]
set_property src_info {type:XDC file:1 line:49 export:INPUT save:INPUT read:READ} [current_design]
set_property PACKAGE_PIN Y21 [get_ports {okUHU[18]}]
set_property src_info {type:XDC file:1 line:50 export:INPUT save:INPUT read:READ} [current_design]
set_property PACKAGE_PIN P17 [get_ports {okUHU[19]}]
set_property src_info {type:XDC file:1 line:51 export:INPUT save:INPUT read:READ} [current_design]
set_property PACKAGE_PIN U20 [get_ports {okUHU[20]}]
set_property src_info {type:XDC file:1 line:52 export:INPUT save:INPUT read:READ} [current_design]
set_property PACKAGE_PIN N17 [get_ports {okUHU[21]}]
set_property src_info {type:XDC file:1 line:53 export:INPUT save:INPUT read:READ} [current_design]
set_property PACKAGE_PIN N14 [get_ports {okUHU[22]}]
set_property src_info {type:XDC file:1 line:54 export:INPUT save:INPUT read:READ} [current_design]
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

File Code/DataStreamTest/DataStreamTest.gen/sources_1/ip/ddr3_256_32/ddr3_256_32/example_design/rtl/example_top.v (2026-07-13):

//*****************************************************************************


// (c) Copyright 2023 Advanced Micro Devices, Inc. All rights reserved.


//


// This file contains confidential and proprietary information


// of AMD and is protected under U.S. and international copyright


// and other intellectual property laws.


//


// DISCLAIMER


// This disclaimer is not a license and does not grant any


// rights to the materials distributed herewith. Except as


// otherwise provided in a valid license issued to you by


// AMD, and to the maximum extent permitted by applicable


// law: (1) THESE MATERIALS ARE MADE AVAILABLE "AS IS" AND


// WITH ALL FAULTS, AND AMD HEREBY DISCLAIMS ALL WARRANTIES


// AND CONDITIONS, EXPRESS, IMPLIED, OR STATUTORY, INCLUDING


// BUT NOT LIMITED TO WARRANTIES OF MERCHANTABILITY, NON-


// INFRINGEMENT, OR FITNESS FOR ANY PARTICULAR PURPOSE; and


// (2) AMD shall not be liable (whether in contract or tort,


// including negligence, or under any other theory of


// liability) for any loss or damage of any kind or nature


// related to, arising under or in connection with these


// materials, including for any direct, or any indirect,


// special, incidental, or consequential loss or damage


// (including loss of data, profits, goodwill, or any type of


// loss or damage suffered as a result of any action brought


// by a third party) even if such damage or loss was


// reasonably foreseeable or AMD had been advised of the


// possibility of the same.


//


// CRITICAL APPLICATIONS


// AMD products are not designed or intended to be fail-


// safe, or for use in any application requiring fail-safe


// performance, such as life-support or safety devices or


// systems, Class III medical devices, nuclear facilities,


// applications related to the deployment of airbags, or any


// other applications that could lead to death, personal


// injury, or severe property or environmental damage


// (individually and collectively, "Critical


// Applications"). Customer assumes the sole risk and


// liability of any use of AMD products in Critical


// Applications, subject only to applicable laws and


// regulations governing limitations on product liability.


//


// THIS COPYRIGHT NOTICE AND DISCLAIMER MUST BE RETAINED AS


// PART OF THIS FILE AT ALL TIMES.


//


//*****************************************************************************


//   ____  ____


//  /   /\/   /


// /___/  \  /    Vendor             : AMD


// \   \   \/     Version            : 4.2


//  \   \         Application        : MIG


//  /   /         Filename           : example_top.v


// /___/   /\     Date Last Modified : $Date: 2011/06/02 08:35:03 $


// \   \  /  \    Date Created       : Tue Sept 21 2010


//  \___\/\___\


//


// Device           : 7 Series


// Design Name      : DDR3 SDRAM


// Purpose          :


//   Top-level  module. This module serves as an example,


//   and allows the user to synthesize a self-contained design,


//   which they can be used to test their hardware.


//   In addition to the memory controller, the module instantiates:


//     1. Synthesizable testbench - used to model user's backend logic


//        and generate different traffic patterns


// Reference        :


// Revision History :


//*****************************************************************************





//`define SKIP_CALIB


`timescale 1ps/1ps





module example_top #


  (





   //***************************************************************************


   // Traffic Gen related parameters


   //***************************************************************************


   parameter PORT_MODE             = "BI_MODE",


   parameter DATA_MODE             = 4'b0010,


   parameter TST_MEM_INSTR_MODE    = "R_W_INSTR_MODE",


   parameter EYE_TEST              = "FALSE",


                                     // set EYE_TEST = "TRUE" to probe memory


                                     // signals. Traffic Generator will only


                                     // write to one single location and no


                                     // read transactions will be generated.


   parameter DATA_PATTERN          = "DGEN_ALL",


                                      // For small devices, choose one only.


                                      // For large device, choose "DGEN_ALL"


                                      // "DGEN_HAMMER", "DGEN_WALKING1",


                                      // "DGEN_WALKING0","DGEN_ADDR","


                                      // "DGEN_NEIGHBOR","DGEN_PRBS","DGEN_ALL"


   parameter CMD_PATTERN           = "CGEN_ALL",


                                      // "CGEN_PRBS","CGEN_FIXED","CGEN_BRAM",


                                      // "CGEN_SEQUENTIAL", "CGEN_ALL"


   parameter CMD_WDT               = 'h3FF,


   parameter WR_WDT                = 'h1FFF,


   parameter RD_WDT                = 'h3FF,


   parameter SEL_VICTIM_LINE       = 0,


   parameter BEGIN_ADDRESS         = 32'h00000000,


   parameter END_ADDRESS           = 32'h00ffffff,


   parameter PRBS_EADDR_MASK_POS   = 32'hff000000,





   //***************************************************************************


   // The following parameters refer to width of various ports


   //***************************************************************************


   parameter CK_WIDTH              = 1,


                                     // # of CK/CK# outputs to memory.


   parameter nCS_PER_RANK          = 1,


                                     // # of unique CS outputs per rank for phy


   parameter CKE_WIDTH             = 1,


                                     // # of CKE outputs to memory.


   parameter DM_WIDTH              = 4,


                                     // # of DM (data mask)


   parameter ODT_WIDTH             = 1,


                                     // # of ODT outputs to memory.


   parameter BANK_WIDTH            = 3,


                                     // # of memory Bank Address bits.


   parameter COL_WIDTH             = 10,


                                     // # of memory Column Address bits.


   parameter CS_WIDTH              = 1,


                                     // # of unique CS outputs to memory.


   parameter DQ_WIDTH              = 32,


                                     // # of DQ (data)


   parameter DQS_WIDTH             = 4,


   parameter DQS_CNT_WIDTH         = 2,


                                     // = ceil(log2(DQS_WIDTH))


   parameter DRAM_WIDTH            = 8,


                                     // # of DQ per DQS


   parameter ECC                   = "OFF",


   parameter ECC_TEST              = "OFF",


   //parameter nBANK_MACHS           = 4,


   parameter nBANK_MACHS           = 4,


   parameter RANKS                 = 1,


                                     // # of Ranks.
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

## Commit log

2026-07-13 Commit of mechanical and electrical files
    [Altium_BOM_Template.xlsx, Altium_Librairie_PCB_Default.PcbLib, Altium_Librairie_Schematic_Default.SchLib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]
2026-07-13 Commit of code
    [Emager.csv, Silver_Ink.csv]
2026-08-06 A lot of different stuff
    [3-2492104-6.PcbLib, 3-2492104-6.SchLib, Altium_BOM_Template.xlsx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]
2026-08-10 A lot of modifications and Gerber generation
    [Bill of Materials-RHD2164_USBC_V2.xlsx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]
2026-08-11 BOM Preparation
    [Breakout_Boards_Panel.GBL, Breakout_Boards_Panel.GBO, Breakout_Boards_Panel.GBP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]
2026-08-13 More BOM preparation
    [BOM V1.xlsx]
2026-09-04 New version of PCB with the change from RHD2164 to RHD2132
    [3-2492104-6.PcbLib, 3-2492104-6.SchLib, Altium_BOM_Template.xlsx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]
2026-09-04 Add project overview and specifications to README
    Added detailed project description, objectives, specifications, applications, and file architecture for the ultra-high-density EMG electrode array project.
2026-09-04 Include diagrams for PCB usage clarification
    Added images to enhance understanding of PCB usage.
2026-09-09 Corrected ZIF orientation and started 3D designs
    [BTE-040-01-F-D-A.stp, CONNECTOR.PcbLib, FPGA.SchDoc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]
2026-09-09 Changed ZIF orientation on electrode_breakout
    [DB_Panel.GBL, DB_Panel.GBO, DB_Panel.GBP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]
2026-09-11 More mechanical designs
    [Board_1.step.SLDASM, Board_2.step.SLDASM, E10_1.step.SLDASM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]
2026-09-23 3D CAD and Corrections after PCB review
    [12401610E4#2A.SchLib, 12401610E4%232A--3DModel-STEP-533217.STEP, AMPHENOL_12401610E4#2A.PcbLib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]
2026-09-23 BOM preparation V3
    [FPGA.SchDoc, INTAN_Interface.SchDoc, Onboard_IO.SchDoc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]
2026-10-07 Made FPC Panel and 3D Cad modifications
    [CONNECTOR.SchLib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]
2026-10-07 Preparation des documents de tests et de protocoles
    [Data_Acquisition_Tests.xlsx, Integration_Tests.xlsx, Sample_Tests.xlsx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]
2026-10-08 Correction of the progess meeting powerpoint
2026-11-10 Updated and 1st print mechanichal design
